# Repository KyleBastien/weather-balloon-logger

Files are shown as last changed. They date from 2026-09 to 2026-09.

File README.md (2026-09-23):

# Weather Balloon Logger LightHAB carrier

This repository contains a hand-solderable through-hole carrier for the QRP Labs LightHABTracker 1.0 and SparkFun OpenLog. LightHAB's exposed 3.3 V rail powers the logger directly.

| Directory | Contents |
| --- | --- |
| `docs/` | Electrical, mechanical, BOM, purchasing, and release records |
| `library/` | Project KiCad symbols and through-hole footprints |
| `firmware/` | LightHAB upstream integration scaffold and test plan |
| `outputs/` | Review renders, fit sheet, BOM, Gerbers, drill, DXF, and STEP |
| `scripts/` | Deterministic board rebuild, export, and audit tools |

## Project release status

This repository now contains the Weather Balloon Logger carrier design and its
review exports. It is **not yet released for fabrication** because the purchased LightHAB must be measured before its connector and mounting geometry can be finalized. See
[`docs/FABRICATION_READINESS.md`](docs/FABRICATION_READINESS.md) for the exact
engineering-prototype and flight-candidate gates.

## Working locally

The CLI needs no account and no cloud:

```bash
npm i -g copperhead
copperhead check          # ERC, DRC, and doc drift. No model, no network.
copperhead do "..."       # propose, edit, verify, commit
```

The current PCB has zero SMD pads, zero unconnected items, and a prominent no-fabrication warning in the provisional module area.

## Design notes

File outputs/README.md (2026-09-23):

# Generated review outputs

These files reflect the LightHABTracker carrier source at the current commit. They are **review artifacts, not a fabrication release** because the tracker interface and mounting geometry are provisional.

## Drawings

- `board.svg`: standard top board plot.
- `renders/weather-balloon-logger.svg`: schematic plot.
- `renders/board-full-color.svg`: colored top view including copper, through-hole pads, silkscreen, outline, and the provisional LightHAB envelope/keepouts.
- `renders/board-green-top.png`: flat green-board contrast render with no 3D component models.
- `renders/board-fit-check-1to1.pdf`: true-scale fit sheet. Print at 100% / Actual Size and verify the 90.0 × 80.0 mm outline before use.
- `board.step`: board geometry export; component-model completeness is not required for this fit stage.

The front silkscreen includes the coffee artwork and the required `UNVERIFIED LIGHTHAB FIT - DO NOT FABRICATE` warning.

## BOM and order list

- `BOM.csv` is generated from schematic MPN fields and contains 10 populated through-hole references.
- `jlcpcb-bom.csv` is a convenient grouped reference only; this project is intended for hand assembly and is not an assembly-service release.
- `fit-check-order-list.xlsx` separates safe buy-now items from held interfaces/fabrication. The three PNG files are visual checks of every worksheet.

## Gerbers

`gerbers/` is an engineering review export that also contains empty paste and back-silkscreen plots. Do not upload it wholesale. After the measured fit gate passes, create and independently inspect a fabricator-specific ZIP containing only the requested copper, mask, front silk, outline, drill, and job files.

See `../docs/FABRICATION_READINESS.md` for the remaining gates.

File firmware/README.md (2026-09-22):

# Weather Balloon Logger firmware integration scaffold

This scaffold is the carrier-side patch seed for the LightHABTracker 1.0 ATSAMD21G18 firmware. It is not a standalone, compiled flight image: the final changes must be rebased onto and built with the upstream LightHABTracker source pinned in `DEVPLAN.md`.

`docs/PINOUT.md` is the pin source of truth. Regenerate `include/pins.h` from the repository root with:

```text
python firmware/tools/generate_pins.py
```

The generator fails closed unless J2.1 remains UART TX on A1/PB08 and J2.2 remains the active-low activity LED on A2/PB09.

## Intended behavior

`WeatherBalloonLogger.ino` preloads A2 HIGH before making it an output, initializes a polling TX-only SERCOM4 UART on A1/PB08, then writes a heading and one deterministic record to OpenLog while pulsing the LED low. OpenLog TXO is unused.

LightHAB's upstream firmware—not this carrier scaffold—owns OUT1 cutdown timing, arming, and safety. No carrier code directly commands the pyro output.

## Boundaries

- `openlog` provides the proposed TX-only UART implementation without taking the occupied GPS UART.
- `telemetry_stub` marks the seam where upstream LightHAB telemetry must be supplied.
- The LED pulse reports that bytes were sent; it cannot prove that the microSD card committed them.
- A1/PB08 and A2/PB09 appeared unused in the inspected upstream source, but that must be reconfirmed during the pinned-source integration and build.

See `DEVPLAN.md` for the exact upstream baseline and qualification gates.

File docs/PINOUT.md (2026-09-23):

# Pinout — Weather Balloon Logger harness

Authoritative LightHABTracker 1.0 carrier assignment. J2 is the official known nine-position order A1, A2, 3V3, GND, SCL, SDA, SCK, MISO, MOSI. A1/PB08 is one-way OpenLog UART TX; A2/PB09 is active-low LED_N. The PCB implements this mapping with provisional connector and mounting geometry pending measurement of the purchased tracker.

## Host interface J2

| Refdes | Pin | Net | Host mapping / rationale |
| --- | --- | --- | --- |
| J2 | 1 | UART_TX | A1/PB08 one-way host TX through R4 to OpenLog RXI. |
| J2 | 2 | LED_N | A2/PB09 active-low LED sink; R2 pulls it to 3V3 so reset/high-impedance defaults D1 off. |
| J2 | 3 | 3V3 | LightHAB regulated 3.3 V for OpenLog VCC, C1/C2, the LED anode path, and R2 pull-up. |
| J2 | 4 | GND | Common signal and power return. |
| J2 | 5 | NC | Physical SCL contact intentionally unused on this carrier. |
| J2 | 6 | NC | Physical SDA contact intentionally unused on this carrier. |
| J2 | 7 | NC | Physical SCK contact intentionally unused on this carrier. |
| J2 | 8 | NC | Physical MISO contact intentionally unused on this carrier. |
| J2 | 9 | NC | Physical MOSI contact intentionally unused on this carrier. |

The A1/PB08 and A2/PB09 assignments follow the requested LightHAB interface contract. R2 is the intentional hardware reset-default-off path for the active-low LED; the former PCF8574 and cutdown-driver reset behavior no longer applies.

## Complete schematic pin/net table

| Refdes | Pin | Net | Function / intentional absence |
| --- | --- | --- | --- |
| J2 | 1 | UART_TX | A1/PB08 host TX to R4. |
| J2 | 2 | LED_N | A2/PB09 active-low LED cathode/sink node. |
| J2 | 3 | 3V3 | LightHAB regulated 3.3 V. |
| J2 | 4 | GND | Common return. |
| J2 | 5 | NC | Physical SCL contact intentionally unused. |
| J2 | 6 | NC | Physical SDA contact intentionally unused. |
| J2 | 7 | NC | Physical SCK contact intentionally unused. |
| J2 | 8 | NC | Physical MISO contact intentionally unused. |
| J2 | 9 | NC | Physical MOSI contact intentionally unused. |
| A1 | 1 | NC | BLK orientation pin intentionally unused. |
| A1 | 2 | GND | OpenLog ground. |
| A1 | 3 | 3V3 | OpenLog VCC directly from LightHAB J2.3. |
| A1 | 4 | NC | TXO intentionally unused. |
| A1 | 5 | OPENLOG_RXI | RXI receives host bytes through R4. |
| A1 | 6 | NC | GRN orientation pin intentionally unused. |
| C1 | 1 | 3V3 | OpenLog bulk bypass. |
| C1 | 2 | GND | Bypass return. |
| C2 | 1 | 3V3 | OpenLog high-frequency bypass. |
| C2 | 2 | GND | Bypass return. |
| R4 | 1 | UART_TX | Host side of UART back-power limiter. |
| R4 | 2 | OPENLOG_RXI | OpenLog receive side. |
| R1 | 1 | 3V3 | LED current-limiter supply. |
| R1 | 2 | LED_A | D1 anode feed. |
| D1 | 1 | LED_N | Cathode driven active-low by J2.2. |
| D1 | 2 | LED_A | Anode from R1. |
| R2 | 1 | 3V3 | Reset-default-off pull-up supply. |
| R2 | 2 | LED_N | 100 kΩ pull-up keeps D1 off while J2.2 is high-impedance. |
| J3 | 1 | OUT1 | LightHAB pyro output passed directly to J5.1; rating unverified. |
| J3 | 2 | GND | LightHAB pyro return passed directly to J5.2. |
| J5 | 1 | OUT1 | Direct LightHAB OUT1 cutdown output. |
| J5 | 2 | GND | Direct LightHAB pyro return. |

## Intentional absences

- No host RX path: OpenLog TXO remains unused.
- No VBATT interface or carrier logger regulator: J1 and A2 are intentionally removed because OpenLog accepts direct 3.3 V power.
- No I2C expander: U1 and C3 are intentionally removed because LightHAB A2/PB09 drives the LED directly.
- No carrier pyro driver: U2, Q1, R3, C4, and C5 are intentionally removed because LightHAB OUT1/GND passes directly to J5; its switching and current rating remain unverified.
- No carrier RF connectors or nets are present; the LightHAB onboard SMA connectors remain accessible inside the documented mechanical keepouts.
- SCL, SDA, SCK, MISO, and MOSI remain physically present on J2.5–J2.9 and are intentional no-connects.
- The schematic and PCB are synchronized electrically; the LightHAB mounting/connector geometry remains explicitly provisional and blocks fabrication.

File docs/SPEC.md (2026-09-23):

# Specification — Weather Balloon Logger carrier

This carrier adapts a LightHABTracker 1.0 to a SparkFun OpenLog, an activity LED, and a removable nichrome cutdown lead. The LightHABTracker remains the only flight computer and supplies GPS, APRS/WSPR radios, a 3×AA battery holder, two SMA connectors, and two pyro channels.

## 1. Architecture

| Item | Requirement | Status |
| --- | --- | --- |
| Host | LightHABTracker 1.0, ATSAMD21G18 | Selected |
| Flight duration | At least 4 h with GPS and flight firmware continuously available | Required; cold-load test pending |
| Battery | Three Energizer L91 AA cells in the tracker holder | Selected |
| Logger | SparkFun OpenLog DEV-13955, one-way UART receive | Selected |
| Logger supply | LightHAB J2.3 regulated 3V3, direct | Accepted assumption; bench validation required |
| Cutdown | LightHAB onboard OUT1 pyro channel passed directly to J5 | Selected; electrical rating unverified |
| Carrier assembly | All populated carrier parts directly soldered through-hole; no SMD pads | Required |

The tracker is approximately 56 × 75 mm and 36 g without batteries or antennas according to the vendor. Exact hole centers, drills, header pitch and coordinates, maximum battery-holder height, and connector/switch geometry are not published and must be measured on a purchased unit before fabrication.

## 2. Power

LightHAB accepts 2.7–16 V and carries its own 3×AA holder. The carrier does not contain a second battery holder, master switch, or logger regulator. J2.3 `3V3` directly powers OpenLog A1, C1/C2 bypass, and the activity LED path. Common ground joins J2, A1, J3, and J5. SparkFun specifies OpenLog VCC at 3.3–12 V and recommends 3.3–5 V, so 3.3 V is valid for the logger; this design accepts the unverified assumption that LightHAB can supply the approximately 20–23 mA active-write load plus transient margin.

| Parameter | Requirement |
| --- | --- |
| Mission energy | Demonstrate ≥4 h at the real cold-temperature and RF duty profile |
| OpenLog idle/write | Qualify ≤7 mA idle and ≤25 mA writing |
| LightHAB 3V3 | Remain in tolerance through OpenLog startup, card inrush, and writes |
| LED reset state | Off; R2=100 kΩ pulls active-low `LED_N` to 3V3 |
| OpenLog source | Direct J2.3 3V3; no carrier regulator |

## 3. Interfaces

### J2 — LightHAB extended pins

J2 is a directly soldered 1×9 through-hole interface in this order:

| Pin | LightHAB signal | Carrier use |
| --- | --- | --- |
| 1 | A1 / PB08 | `UART_TX` through R4 to OpenLog RXI |
| 2 | A2 / PB09 | Active-low `LED_N` |
| 3 | 3V3 | OpenLog VCC/C1/C2 plus LED supply and R2 pull-up |
| 4 | GND | Common return |
| 5 | SCL | Intentional no-connect |
| 6 | SDA | Intentional no-connect |
| 7 | SCK | Intentional no-connect |
| 8 | MISO | Intentional no-connect |
| 9 | MOSI | Intentional no-connect |

A1/PB08 and A2/PB09 appear unused in the reviewed upstream firmware at commit `797b78d120b0e844f60798b88dfa3735f27e89da`, but integration must be rebased and retested against the exact firmware shipped on the purchased tracker.

### OpenLog and activity LED

OpenLog is receive-only: J2.1 → R4 1 kΩ → A1 RXI. A1 TXO is intentionally unused. J2.3 supplies 3.3 V directly to A1 VCC and local C1/C2 bypass. The LED path is 3V3 → R1 1 kΩ → D1 → `LED_N`; firmware drives J2.2 low during activity. R2 keeps it off while the pin is high-impedance at reset. Activity indicates firmware intent to log, not confirmed SD media completion.

### Cutdown

J3 receives LightHAB OUT1/GND and connects directly to the same pins on J5, a horizontal JST-XH connector. The carrier adds no MOSFET, gate driver, or high-current power path. OUT1 polarity, switching topology, pulse duration, current capability, default state, and fault behavior are **UNVERIFIED**. Do not connect nichrome until those properties and the complete harness are bench-tested with a current-limited supply and inert load.

### Antennas

Both antenna connections remain entirely on the LightHABTracker. The carrier contains no SMA connector and no RF trace. The PCB must keep mechanical clearance below and around both onboard SMA connectors and their cable bend volumes.

## 4. Firmware allocation

- A1/PB08: SERCOM4 UART TX to OpenLog.
- A2/PB09: active-low activity LED; write HIGH before configuring OUTPUT to avoid a reset flash.
- LightHAB D4/D5 and the vendor pyro implementation remain owned by upstream firmware. OUT1 is selected for cutdown.
- SCL, SDA, SCK, MISO, and MOSI are not used by the carrier.
- The local firmware is an integration/qualification scaffold, not a replacement for the complete LightHAB flight firmware.

## 5. Mechanical and environment

The carrier outline is 90 × 80 mm. Reserve a provisional 56 × 75 mm LightHAB zone on the right side with the LightHAB component face outward and its battery holder between module and carrier. Use provisional 18–20 mm board-to-board clearance. Place carrier parts on the left wing and keep the OpenLog microSD card accessible. Align the LightHAB USB connector and two SMA connectors with board edges and preserve plug/cable access.

All LightHAB mounting holes and mating interface pads in this revision are photo-derived placeholders and must be labeled **UNVERIFIED — DO NOT FABRICATE**. Final placement requires a purchased module or an official dimensioned drawing.

Qualification temperature remains −40 °C to +40 °C unless the mission profile establishes a wider range. Cold-soak the complete powered stack, batteries, logger, SD card, connectors, and cutdown harness.

## 6. Release gates

Before a fit-test PCB:

1. Measure the LightHAB outline, four hole centers and drills, 1×9 pitch/coordinates/drills, J3 pad coordinates/drills, holder height, and maximum component height.
2. Confirm mounting orientation and USB/SMA/cable access.
3. Confirm LightHAB 3V3 remains in tolerance while OpenLog starts and writes at the cold/voltage extremes.
4. Confirm OUT1/GND polarity, voltage, current limit, switching topology, default state, and supported pulse duration.
5. Reconcile those measurements into the footprint, reroute, and regenerate 1:1 plots.

Before fabrication, additionally complete DRC/ERC, footprint-vs-purchased-part checks, cold/power tests, pyro firing tests, firmware integration tests, and a physical 1:1 paper fit check. Until those gates pass, generated fabrication files are engineering previews only.

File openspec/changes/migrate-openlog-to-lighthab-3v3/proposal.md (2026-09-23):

# Proposal: migrate-openlog-to-lighthab-3v3

> Marker: AUTO (autonomous mode; auto-approved, reviewable after the fact)

## Why

The user accepts direct OpenLog power from LightHAB J2.3 3V3, eliminating the separate VBATT-fed Pololu regulator path and its obsolete fixed-5V claims while retaining a bench-validation gate for the unverified host-rail capacity.

## What Changes

- Remove J1, A2, VBATT, and LOGGER_5V from schematic intent and schematic capture.
- Connect A1.3, C1.1, C2.1, R1.1, and R2.1 to the existing J2.3 3V3 net.
- Preserve UART, active-low LED, J3/J5 OUT1, GND, intentional no-connects, and through-hole choices.
- Update BOM, specification, subsystem, pinout, and affected constraint entries to describe direct LightHAB 3V3 power.
- Record SparkFun OpenLog VCC as 3.3–12 V, recommended 3.3–5 V, with about 20–23 mA active-write current; retain LightHAB 3V3 capacity as an accepted assumption requiring bench validation.
- Remove J1/A2 from the PCB, route J2.3 directly to A1/C1/C2, update the 3V3 silkscreen label, and regenerate all review/manufacturing outputs.
- Synchronize the BOM, fit-check order workbook, readiness checklist, footprint audit, and deterministic build/export scripts; leave firmware and historical change records intact except for new append-only entries.

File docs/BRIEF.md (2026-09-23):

# Weather Balloon Logger carrier brief

Build a hand-solderable through-hole carrier around the QRP Labs LightHABTracker 1.0. LightHAB remains the GPS/APRS/WSPR host, supplies its own 3×AA battery holder and antenna connectors, and owns the two pyro outputs.

The carrier shall:

- mount the tracker once its exact geometry is measured;
- power a SparkFun OpenLog with headers directly from LightHAB J2.3 3V3, accepting the host-rail-capacity assumption until bench validation;
- send telemetry from A1/PB08 to OpenLog RXI through a 1 kΩ series resistor;
- use A2/PB09 as an active-low write-attempt LED with a hardware 100 kΩ reset-default-off pull-up;
- pass LightHAB OUT1/GND directly to a soldered JST-XH cutdown connector;
- contain only through-hole soldered parts, with no SMD pads or carrier RF routing;
- preserve access/keepouts for LightHAB USB, SMA connectors, battery holder, and solder joints;
- remain explicitly blocked from fabrication until the purchased tracker is measured and passes a 1:1 exact-parts fit check.

The carrier does not provide sockets, a second battery holder, a second power switch, an I²C expander, an external pyro MOSFET/driver, or carrier SMA connectors.

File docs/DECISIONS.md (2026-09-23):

- 2026-09-16 Use the exact C&K `7101SYZQE` and hand-solder its `Z` lugs directly into project footprint `WeatherBalloon:SW_CK_7101SYZQE`. Use 2.30 x 1.10 mm plated slots on 4.70 mm centers for the published nominal 2.03 x 0.76 mm lugs, and link the matching downloaded STEP model. Model the top-side SparkFun OpenLog with `WeatherBalloon:SparkFun_OpenLog_DEV-13712_Carrier`, whose 15.24 x 19.05 mm body comes from SparkFun's official dimensional drawing. | why: All off-board parts are intentionally direct-soldered for home assembly; the slot footprint preserves that choice while adding practical insertion clearance. The generic OpenLog header footprint omitted the module body and Copilot's 23 x 14 mm size was incorrect. | affects: SW1, A1, fp-lib-table, library/, schematic.intent.json, weather-balloon-logger.kicad_sch, docs/FOOTPRINT_AUDIT.md, next Copperhead layout pass
- 2026-09-15 [run 2026-09-15T20-57-58-683Z] Size the flight pack as 3s L91 for energy; allow 4s only if LightAPRS-W 2.0 UVLO/VIN cannot run to 3s EOD (3.0 V). Do not add cells for amp-hours. | why: Series cells do not add mAh; ASSUMED 800 mAh flight load vs ≥1600 mAh usable after cold derate is already met by one L91 string. | affects: docs/SPEC.md §2.1–2.2, power.series_cells, power.flight_energy_mAh, power.pack
- 2026-09-15 [run 2026-09-15T20-57-58-683Z] Prefer a low-side MOSFET that is fully enhanced at 3.3 V Vgs for nichrome cutdown; do not commit IRLZ44N or a 3.3 V relay module without an explicit later decision. | why: IRLZ44N Rds(on) is specified at 5 V Vgs so it may not fully turn on from the ATSAMD21G18 3.3 V GPIO; a relay adds coil Iq and vibration risk versus a specified logic-level FET plus intentional gate pulldown. | affects: docs/SPEC.md §5, cutdown.vgs_fully_on_V, cutdown.load_current_A, docs/BOM.md
- 2026-09-15 [run 2026-09-15T20-57-58-683Z] This PCB is a harness only: no second MCU, no carrier RTC, no USB-serial bridge, no L91 charger, no 5 V USB as a flight source. | why: Firmware, GPS, and radios live on LightAPRS-W 2.0; OpenLog is the logger; L91 cells are primary. Missing those blocks is intentional, not an omission. | affects: docs/SPEC.md §4, §6, §8
- 2026-09-15 [run 2026-09-15T22-37-07-258Z] Freeze the carrier as a harness-only block diagram in docs/SUBSYSTEMS.md: 3s L91 (4s only if host UVLO), SW1 breaks pack+, VIN to LightAPRS-W 2.0, 3V3 fan-out to OpenLog/LED/FET gate, UART to OpenLog, dual downward 50 Ω SMA, low-side logic-level cutdown FET with intentional gate pulldown; no GPIO assignments this stage. | why: Locks SPEC budgets before schematic so a later part cannot satisfy voltage/package while blowing Iq, Vgs-at-3.3 V, strapping, or SMA keepout; IRLZ44N and 3.3 V relay remain uncommitted. | affects: docs/SUBSYSTEMS.md, docs/SPEC.md §1–§8, power.*, cutdown.*, antenna.*, openlog.vcc_V, docs/PINOUT.md (intentionally absent)
- 2026-09-15 [run 2026-09-15T23-48-22-724Z] Represent the off-board LightAPRS-W 2.0 at J2 with installed Connector_Generic:Conn_01x07 and represent A1 OpenLog with installed Connector_Generic:Conn_01x06; do not invent unavailable named module symbols or assign host GPIOs in part selection. | why: Neither module name exists in the installed KiCad 10 libraries, while the installed generic connector symbols expose authoritative pins and preserve a capturable stage-4 design pending the mandatory strapping check. | affects: docs/BOM.md, J2, A1, future docs/PINOUT.md and schematic capture
- 2026-09-15 [run 2026-09-15T23-48-22-724Z] Select Q1 AO3400A in SOT-23 as the conditional cutdown FET and SW1 7101MD9CQE as the conditional pack-positive mechanical switch, with every MPN remaining UNVERIFIED until the BOM acceptance checks pass. | why: AO3400A has an installed exact symbol with G/S/D pins 1/2/3 and is specified in the 2.5–3.3 V gate-drive class, unlike IRLZ44N; the switch path must be verified for the full 2 A burst and true pack-positive disconnect. | affects: docs/BOM.md, Q1, SW1, cutdown.vgs_fully_on_V, cutdown.load_current_A, power.switch_off_current_uA
- 2026-09-15 [run 2026-09-15T23-53-19-080Z] Keep LightAPRS-W 2.0 and OpenLog as off-board functional parts but capture them through tool-verified installed generic connector symbols; normalize D1's schematic Value to the component value LTST-C190KGKT and keep descriptive text only in the BOM Rationale. | why: Named LightAPRS-W 2.0 and OpenLog symbols are absent from this KiCad 10 installation, while the selected connector, switch, coax, AO3400A, LED, resistor, and capacitor symbols have authoritative single-unit package pins; component-only Values prevent stage-4 text collisions. | affects: docs/BOM.md; J2; A1; D1; future stage-4 schematic capture
- 2026-09-15 [run 2026-09-15T23-55-27-968Z] Retain the complete stage-3 BOM selections and capture the unavailable named LightAPRS-W 2.0 and OpenLog modules through freshly verified installed generic connector symbols; keep every MPN UNVERIFIED and every host GPIO unassigned. | why: Fresh library searches confirm the named module symbols are absent while the selected connector, coax, switch, AO3400A, LED, resistor, and capacitor lib_ids have authoritative package pins; deferring GPIOs preserves the mandatory strapping check and the BOM acceptance holds preserve the 2 mA idle and leakage budgets. | affects: docs/BOM.md; J1-J5; SW1; A1; Q1; D1; R1-R3; C1-C2; future docs/PINOUT.md and schematic capture
- 2026-09-16 [run 2026-09-16T02-41-32-150Z] Assign LightAPRS A1/PB08 to one-way SERCOM4 UART_TX and A0 to CUTDOWN_CTRL; leave J2 pins 5–6 and OpenLog TXO intentionally unconnected. | why: Only A0 and A1 are confirmed free dedicated GPIOs; OpenLog receive-back is optional, while cutdown requires an independent default-off control without reusing occupied GPS, radio, I2C, or SPI pins. | affects: J2, A1, UART_TX, CUTDOWN_CTRL, docs/PINOUT.md, docs/BOM.md, docs/SPEC.md, docs/SUBSYSTEMS.md
- 2026-09-16 [run 2026-09-16T02-41-32-150Z] Wire the write-activity indicator as 3V3 through R1 and D1 into UART_TX, so idle-high is OFF and low transmitted bits illuminate D1. | why: This produces a visible indication for every transmitted log record while using no third host GPIO and preserving the LED-off leakage budget; it is explicitly a transmit proxy rather than proof of SD-media commit. | affects: D1, R1, UART_TX, LED_A, docs/PINOUT.md, docs/BOM.md, docs/SPEC.md, docs/SUBSYSTEMS.md
- 2026-09-16 [run 2026-09-16T02-41-32-150Z] Accept the deterministic drafter's synthesized copperhead_power rail and PWR_FLAG symbols as engine-local infrastructure, while treating the 15 BOM symbols as the procurement-relevant symbol set. | why: verify_symbols confirmed all BOM library symbols and pins; its remaining wrong/no-library messages refer only to generated named-rail helpers, and substituting suggested converter or diode parts would be electrically false. | affects: weather-balloon-logger.kicad_sch, PACK_IN, PACK_SW, 3V3, GND, CUTDOWN_DRAIN
- 2026-09-16 [run 2026-09-16T02-51-31-754Z] Use an 80 × 70 mm first-draft outline with J1/J5 on the left edge, J2 on the top edge, and J3/J4 on the bottom payload-facing edge; keep the OpenLog/decoupling cluster near J2, the cutdown cluster near J5, and J6 centered between the two RF branches. | why: This separates high-current cutdown hardware from the two ≥5 mm SMA clearance envelopes while keeping decoupling, gate control, and RF stubs locally short. | affects: weather-balloon-logger.kicad_pcb, J1-J6, A1, C1-C2, Q1, R1-R3, D1, LAYOUT.md
- 2026-09-16 [run 2026-09-16T02-51-31-754Z] Mark every inline stage-5 land pattern as board-local `CopperheadDraft_*` geometry and reserve ESD space without adding uncaptured protection devices. | why: The available workflow can create a DRC-clean coordinate study but cannot truthfully claim hand-authored placeholder pads are verified library/manufacturer land patterns; ESD parts also require leakage, voltage, RF-capacitance, schematic, and BOM decisions before placement. | affects: weather-balloon-logger.kicad_pcb, LAYOUT.md, future schematic/BOM footprint and ESD qualification
- 2026-09-16 [run 2026-09-16T03-07-33-386Z] Preserve the committed Stage 5 coordinate-level board draft after successful readback; do not recreate or reroute it during recovery. Treat every CopperheadDraft_* footprint, the drawn RF clearance envelopes, and the reserved ESD areas as explicitly non-fabrication-ready placeholders exactly as disclosed in LAYOUT.md. | why: The recovered board and LAYOUT.md contain the requested placement, critical routing, keepout intent, and Draft quality disclosure; rebuilding would add risk without correcting a failed artifact. | affects: weather-balloon-logger.kicad_pcb, LAYOUT.md, PCB SVG render, and future footprint/RF/ESD qualification
- 2026-09-16 [run 2026-09-16T03-08-59-062Z] Preserve the recovered Stage 5 coordinate-level PCB draft without rerouting or recreating it; treat all CopperheadDraft_* footprints, drawn RF clearance envelopes, and reserved ESD areas as explicitly non-fabrication-ready exactly as disclosed in LAYOUT.md. | why: Readback confirms the existing PCB already contains the requested 80 × 70 mm placement, edge connectors, local decoupling/cutdown/LED clusters, critical routing, RF envelopes, and a complete Draft quality disclosure, so reconstruction would add risk without fixing a demonstrated defect. | affects: weather-balloon-logger.kicad_pcb, LAYOUT.md, exported PCB SVG, docs/DECISIONS.md
- 2026-09-16 [run 2026-09-16T03-15-06-670Z] Generate the Stage 6 fabrication, outline, STEP, SVG, and consolidated BOM artifacts as pipeline outputs only, retaining every MPN UNVERIFIED marker and an explicit no-fabrication and no-procurement hold. | why: The exports are required for pipeline completeness, but the board still uses placeholder land patterns and has unresolved RF, mechanical, thermal, leakage, temperature, and sourcing qualifications. | affects: outputs/, outputs/BOM.csv, outputs/README.md, weather-balloon-logger.kicad_pcb, docs/BOM.md, docs/LAYOUT.md
- 2026-09-16 [run 2026-09-16T03-17-06-012Z] Use an Arduino SAMD scaffold with vendor CMSIS register access for a polling, transmit-only SERCOM4 UART on A1/PB08; make cutdown initialization on A0-low the first application action and provide a reproducible docs/PINOUT.md-to-pins.h generator. | why: This follows the verified two-pin allocation without stealing the occupied GPS UART or inventing an RX/A2 connection, while preserving reset-time cutdown safety and keeping PINOUT.md authoritative. | affects: firmware/, docs/PINOUT.md, UART_TX, CUTDOWN_CTRL, SERCOM4, A0, A1/PB08
- 2026-09-16 [run 2026-09-16T03-22-16-658Z] Gate hardware bring-up and prototype ordering through unpowered continuity, current-limited power, host/3V3, default-off cutdown, OpenLog/UART, RF, dummy-load, nichrome, environmental, and four-hour mission tests in that order; use existing pads/pins as probe locations and keep the current PCB/MPN fabrication and procurement holds. | why: The ordered gates expose shorts, wrong pinouts, excess idle current, reset-time cutdown hazards, RF defects, and thermal failures before energetic or expensive testing, while avoiding any false implication that draft footprints or UNVERIFIED MPNs are production-ready. | affects: docs/DEVPLAN.md, docs/CHANGELOG.md, prototype procurement, PCB fabrication release, PACK_IN, PACK_SW, 3V3, UART_TX, CUTDOWN_CTRL, CUTDOWN_GATE, CUTDOWN_DRAIN, RF_APRS, RF_WSPR
- 2026-09-16 [run 2026-09-16T04-40-13-377Z] Replace the abstract 7-pin J2 with the verified 11-position LightAPRS-W edge-header order; assign J2.3 A1/PB08 to one-way UART_TX and J2.4 A2/PB09 to direct cutdown, and represent VHF/HF as separate J6/J7 corner contacts. | why: The verified physical module exposes A2/PB09 and places VHF/HF at opposite corners, so the former A0/7-pin/two-pin-RF abstraction could not produce a mechanically or electrically faithful carrier. | affects: J2, J6, J7, UART_TX, CUTDOWN_CTRL, RF_APRS, RF_WSPR, docs/PINOUT.md, docs/BOM.md, firmware pin contract
- 2026-09-16 [run 2026-09-16T04-40-13-377Z] Add U1 PCF8574T at I2C address 0x20 with A0/A1/A2 low, P0 as active-low D1 control, P1–P7 reserved no-connect, INT unused, and C3 100 nF local decoupling. | why: Moving visual indicators to the shared I2C bus preserves A1 for OpenLog and A2 for deterministic direct cutdown while providing seven future GPS-status LED outputs; power-up-high ports keep D1 off at reset. | affects: U1, C3, D1, R1, I2C_SCL, I2C_SDA, LED_N, 3V3, GND
- 2026-09-16 [run 2026-09-16T04-40-13-377Z] Retain the 2.00 mA board-added idle ceiling by allocating at most 1.85 mA to OpenLog, 0.10 mA to U1, and 0.05 mA to all remaining passive/FET/LED-off leakage. | why: Adding an always-powered expander without tightening the former 1.95 mA OpenLog allowance would exceed the documented idle-current budget at worst-case maxima. | affects: power.board_added_idle_mA, power.openlog_idle_mA, power.led_expander_idle_uA, A1, U1, docs/SPEC.md, docs/BOM.md
- 2026-09-16 [run 2026-09-16T04-40-13-377Z] Retain the deterministic drafter's copperhead_power rail and PWR_FLAG helpers unchanged after the host-interface revision. | why: verify_symbols confirms the functional installed symbols including PCF8574T; its remaining library findings are only the already-documented engine-local named-rail infrastructure, and substituting suggested converters, diodes, or crystals would be electrically false. | affects: weather-balloon-logger.kicad_sch, 3V3, GND, PACK_IN, PACK_SW, CUTDOWN_DRAIN, PWR_FLAG
- 2026-09-16 [run 2026-09-16T05-01-15-431Z] Reserve the 32 × 55 mm LightAPRS-W zone at PCB coordinates (124,101)–(156,156), place the direct-mating J2 row on its left long edge, place J6 VHF and J7 HF at opposite lower corners, and keep every other electrical component outside; add four approximate M2 standoff holes pending physical-board confirmation. | why: This permits direct module plug-in while preventing body collisions and preserving outward, separated RF paths to the two bottom-edge SMA jacks. | affects: weather-balloon-logger.kicad_pcb, J2, J6, J7, H1-H4, J3, J4, docs/LAYOUT.md, docs/SUBSYSTEMS.md
- 2026-09-16 [run 2026-09-16T05-47-26-045Z] Use the exact 32.77 x 54.80 mm FACE-UP LightAPRS-W zone with J2 on the matching right long edge, J7/HF bottom-left, J6/VHF bottom-right, J4/WSPR on the left board edge, and J3/APRS on the right board edge; rotate the vendor drawing's approximately 42.73 mm long-axis hole span onto the PCB vertical axis. | why: Direct top-view reproduction prevents the prior left-right mirror error, preserves J6-to-J3 and J7-to-J4 electrical mappings, and gives short uncrossed RF launches while fitting the hole pattern within the 32.77 mm module width. | affects: weather-balloon-logger.kicad_pcb, docs/LAYOUT.md, mechanical.lightaprs_module_zone, J2, J3, J4, J6, J7, H1-H4, RF_APRS, RF_WSPR
- 2026-09-16 [run 2026-09-16T06-19-14-171Z] Place H1-H4 at the measured module coordinates and center J2's exact 2.548 mm-pitch span at x=154.9; shift J7/J6 outward to x=123.7/156.3 at y=154.5 so their copper clears H3/H4 while retaining HF-left and VHF-right. | why: The requested measured hole rectangle and approximate RF-contact centers geometrically conflict, so the RF contacts must move outward slightly to preserve hole clearance without swapping the verified RF mapping. | affects: weather-balloon-logger.kicad_pcb, docs/LAYOUT.md, mechanical.lightaprs_module_zone, H1-H4, J2, J6, J7, RF_APRS, RF_WSPR
- 2026-09-16 [run 2026-09-16T06-19-14-171Z] Move J7/HF and J6/VHF 0.5 mm farther toward the module bottom edge and reroute J2/U1 ground returns around the I2C conductors. | why: The first measured-coordinate placement missed the 0.25 mm NPTH hole-clearance rule and created B.Cu SCL/SDA crossings; the adjusted positions preserve RF side mapping and satisfy explicit DRC geometry. | affects: weather-balloon-logger.kicad_pcb, docs/LAYOUT.md, mechanical.lightaprs_module_zone, J2, J6, J7, I2C_SCL, I2C_SDA, GND, RF_APRS, RF_WSPR
- 2026-09-16 [run 2026-09-16T07-14-10-279Z] Place the horizontal, right-reading `JAVAS Logger` label on F.SilkS centered at (114.5, 118.0) mm using 1.8 mm text and a 0.30 mm stroke. | why: The left-center location is readable while remaining above the reserved ESD area, left of the LightAPRS-W module zone, outside both SMA keepouts, and clear of components, pads, traces, and H1-H4. | affects: weather-balloon-logger.kicad_pcb, docs/LAYOUT.md
- 2026-09-16 [run 2026-09-16T23-23-26-534Z] Place J1 at (107,108) 90°, J5 at (110,141) 90°, and SW1 at (114,108) 0° while retaining their exact real footprints; keep SW1 pad 2 as PACK_IN, pad 1 as PACK_SW, and pad 3 intentionally unconnected. | why: These are the minimum inward/rightward moves that contain all three real courtyards, keep the JST side-entry openings and toggle accessible for hand assembly, and avoid moving any other footprint or changing the outline. | affects: weather-balloon-logger.kicad_pcb; J1; J5; SW1; PACK_IN; PACK_SW; GND; CUTDOWN_DRAIN; docs/FOOTPRINT_AUDIT.md; docs/LAYOUT.md
- 2026-09-16 [run 2026-09-16T23-23-26-534Z] Retain J1 at (103,108) 90° and J5 at (103,141) 90° after exact rotated-courtyard evaluation; move only SW1 to (114,108) 0°, route PACK_SW around SW1 pad 3 and adjacent connector pads, and move only SW1's colliding nonfunctional silk to F.Fab. | why: The first normal DRC proved both JST courtyards already fit at their original edge positions, while the true conflicts came from SW1 clearance and diagonal copper approaches across neighboring through-hole pads. | affects: J1; J5; SW1; PACK_IN; PACK_SW; GND; CUTDOWN_DRAIN; weather-balloon-logger.kicad_pcb; docs/FOOTPRINT_AUDIT.md; docs/LAYOUT.md
- 2026-09-16 [run 2026-09-16T23-31-10-944Z] Place the exact top-side solder-down OpenLog carrier A1 at (171,110) with C1/C2 retained at (168,114)/(164,114), and extend only the board top edge from y=100 to y=91.5. | why: This is the minimum coherent geometry change that puts A1's official body and courtyard outside the fixed LightAPRS zone, exposes the microSD end at an edge, preserves short bypass connections, and leaves all fixed module and RF placement untouched. | affects: weather-balloon-logger.kicad_pcb; A1; C1; C2; GND; 3V3; UART_TX; docs/LAYOUT.md; docs/FOOTPRINT_AUDIT.md
- 2026-09-16 [run 2026-09-16T23-38-07-526Z] Keep J3 at (168,162) and J4 at (112,162) with their exact SMA_Amphenol_132134_Vertical footprints; bring each 0.5 mm RF trace into pad 1 along the connector centerline and join all four pad-2 shields with a symmetric 1.0 mm B.Cu U-fanout to the existing bottom GND trunk. | why: Centerline entry clears the real shield pads and the balanced local fanout removes every dangling/unconnected shield with the smallest routing-only change; released-stackup impedance design, final return vias, and VNA validation remain mandatory. | affects: weather-balloon-logger.kicad_pcb; J3; J4; RF_APRS; RF_WSPR; GND; docs/LAYOUT.md; docs/FOOTPRINT_AUDIT.md
- 2026-09-17 [run 2026-09-17T00-49-26-287Z] Fix the flight pack at exactly three series Energizer L91 cells at 3.0–5.4 V, keep LightAPRS RAW/J2.1 and cutdown J5.1 directly on switched PACK_SW, and dedicate Pololu S7V8F5 item 2123 to OpenLog only with VIN and SHDN on PACK_SW, GND common, and fixed LOGGER_5V from VOUT to A1 VCC. | why: This preserves uninterrupted GPS and the unregulated high-current cutdown path while isolating OpenLog from the LightAPRS 3V3 rail within realistic logger current limits. | affects: current authoritative documentation, constraint registry, BOM, PACK_SW, LOGGER_5V, A1 VCC; schematic and PCB implementation intentionally deferred
- 2026-09-17 Capture A2 and R4 in the schematic while deferring only PCB placement/routing. | why: A deterministic schematic checkpoint proves the split-power and UART back-power contracts before changing crowded board copper. | affects: A2, R4, A1, C1, C2, PACK_SW, LOGGER_5V, UART_TX, OPENLOG_RXI, schematic.intent.json, weather-balloon-logger.kicad_sch
- 2026-09-17 Place A2 at (106,121) 270° and R4 at (159.8,113.3) 90° without moving existing footprints or enlarging the outline. | why: This is the DRC-proven position that clears SW1/J1/J5/R2, the fixed LightAPRS body, and both RF reservations while keeping switched-pack input local and OpenLog UART isolation close to A1. | affects: weather-balloon-logger.kicad_pcb, A2, R4, PACK_SW, LOGGER_5V, GND, UART_TX, OPENLOG_RXI
- 2026-09-17 Replace R4's 0603 footprint with a horizontal DIN0207 axial through-hole footprint on 7.62 mm pitch at (166.62,118), 180°. | why: R4 must be installable as a leaded part through drilled holes for straightforward hand soldering; the new position clears surrounding module and copper geometry. | affects: R4, schematic.intent.json, weather-balloon-logger.kicad_sch, weather-balloon-logger.kicad_pcb, UART_TX, OPENLOG_RXI
- 2026-09-17 [run 2026-09-17T04-30-30-449Z] Move only C4 to (111,125) and C5 to (106.5,129.5), retain their -90 degree orientation, reconnect only LOGGER_5V/GND locally, replace the two KEMET footprint silk rectangles with pad-clear top/bottom strokes, and hide only the colliding U1/R4/C5/R3/Q1/U2 references. | why: These bounded changes clear the reported courtyard, PTH, and legend conflicts without altering pads, fab/courtyard geometry, outline, RF routing, or functional topology. | affects: weather-balloon-logger.kicad_pcb; library/WeatherBalloon.pretty/KEMET_C315C104K5R5TA.kicad_mod; library/WeatherBalloon.pretty/KEMET_C322C475K5R5TA.kicad_mod; C1-C5; C4/C5 LOGGER_5V and GND; U1/R4/J5/U2/R3/Q1/A2 local legend
- 2026-09-17 [run 2026-09-17T04-30-30-449Z] Correct the final cleanup placement to C4 at (109,132.3) with -90 degree orientation and C5 at (106.5,148) with 0 degree orientation; keep C4 adjacent to U2 and C5 entirely above the RF/ESD reservation. | why: The initial candidate intersected A2 and PACK_SW; these corrected coordinates use the DRC-proven free regions beside and below the driver while preserving all fixed footprints and functional nets. | affects: weather-balloon-logger.kicad_pcb; C4; C5; LOGGER_5V; GND
- 2026-09-17 [run 2026-09-17T04-30-30-449Z] Use the final mechanically clean bypass placement C4=(108,133.3) at 0 degrees and C5=(103,115.5) at 0 degrees, with only short local LOGGER_5V/GND connections to existing trunks. | why: Rotating C4 fits it between the fixed A2 and J5 courtyards while keeping it closest to U2; C5 fits between fixed J1 and A2 and stays outside the cutdown and RF reservations. | affects: weather-balloon-logger.kicad_pcb; C4; C5; LOGGER_5V; GND
- 2026-09-17 [run 2026-09-17T04-30-30-449Z] Set the final C4 position to (107.7,133.3) and hide its reference text. | why: A 0.3 mm left shift clears the fixed CUTDOWN_DRIVE trace while retaining the mechanically clean A2/J5/U2 gaps; hiding the reference removes the final A2 legend collision without altering functional silk geometry. | affects: weather-balloon-logger.kicad_pcb; C4; LOGGER_5V; GND; local F.SilkS
- 2026-09-17 [run 2026-09-17T04-30-30-449Z] Correct docs/PINOUT.md to show the existing captured cutdown-driver nets: R2.1=CUTDOWN_DRIVE, Q1.2=CUTDOWN_DRAIN, and Q1.3=GND. | why: The drift checker exposed stale documentation from the earlier direct-drive/AO3400 mapping; the schematic and functional topology remain unchanged. | affects: docs/PINOUT.md; R2; Q1; CUTDOWN_DRIVE; CUTDOWN_DRAIN; GND
- 2026-09-17 [run 2026-09-17T05-14-18-458Z] Add only compact F.SilkS functional and polarity text around the existing placed hardware, preserving every reference designator and all electrical/mechanical geometry. | why: Human-readable field and assembly cues reduce battery, cutdown, module, and RF-port connection errors without changing the verified design. | affects: weather-balloon-logger.kicad_pcb F.SilkS; docs/LAYOUT.md
- 2026-09-17 Refine the functional legend against the assembled 3D view: keep POWER SWITCH and 5V REG visible after installation, mark J5 directly with plus/minus, shorten its CUTDOWN caption, and identify the remote driver caption as `U2 DRIVER - LEFT DIP`. Omit engineering User layers from the color presentation SVG. | why: DRC clearance alone does not guarantee that labels are visible, correctly associated, or uncluttered after assembly. | affects: weather-balloon-logger.kicad_pcb F.SilkS; outputs/renders/board-full-color.svg; docs/LAYOUT.md; outputs/README.md
- 2026-09-21 Use a 90 × 80 mm carrier with a provisional 56 × 75 mm right-side LightHAB zone, components facing outward, the battery holder between boards, and an 18–20 mm provisional stack. | why: Published overall dimensions support an architecture draft, while absent hole/interface dimensions require a visible no-fabrication hold. | affects: weather-balloon-logger.kicad_pcb, J1-J3, H1-H4, docs/LAYOUT.md
- 2026-09-21 Remove all carrier RF and discrete pyro-driver hardware; pass LightHAB OUT1/GND directly from J3 to J5 and reserve only mechanical SMA/USB clearance. | why: LightHAB integrates both radios, SMA connectors, battery holder, and pyro channels; duplicating those blocks would add unverified wiring and inaccessible parts. | affects: J3, J5, OUT1, GND, PCB keepouts
- 2026-09-21 Generate the provisional PCB with a deterministic KiCad Python script and require clean KiCad ERC/DRC, zero unconnected items, zero SMD pads, and visual review. | why: Copperhead validated the bounded proposal but stalled while reasoning over the legacy 6,000-line board, so deterministic regeneration provides a reproducible and independently checked result. | affects: scripts/rebuild_lighthab_board.py, weather-balloon-logger.kicad_pcb
- 2026-09-21 Keep LightHAB's vendor firmware solely responsible for OUT1 cutdown control; the carrier firmware uses A2/PB09 only as an active-low logger activity LED and initializes it HIGH-before-output. | why: The new tracker already contains the pyro channels, so duplicate carrier firing logic creates conflicting ownership and an avoidable safety path. | affects: firmware/, J2.2, D1, R2, J3, J5
- 2026-09-21 Treat all generated manufacturing files as review-only until a purchased LightHABTracker supplies measured connector, hole, battery-holder, USB, and SMA geometry. | why: Public overall dimensions are insufficient to release a mating carrier footprint. | affects: docs/FABRICATION_READINESS.md, outputs/, J1-J3, H1-H4
- 2026-09-22 Remove J1 and A2 and power OpenLog A1 plus C1/C2 directly from LightHAB J2.3 3V3. | why: SparkFun permits 3.3 V OpenLog operation and the user explicitly accepts the unverified LightHAB rail-capacity assumption; removing the separate VBATT/regulator path reduces the carrier part count and interfaces. Bench validation under logger and radio load remains mandatory. | affects: J1, A2, A1, C1, C2, 3V3, VBATT, LOGGER_5V, schematic, PCB, BOM, order list, fabrication gates

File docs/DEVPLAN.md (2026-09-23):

# Development and qualification plan

## Current design

The carrier mounts a LightHABTracker 1.0, powers an OpenLog directly from LightHAB J2.3 3V3, provides an active-low write-attempt LED, and passes LightHAB OUT1/GND directly to J5. The tracker retains its onboard 3×AA holder, dual SMA connectors, radios, GPS, and pyro control. The carrier adds no RF path, logger regulator, or pyro driver.

## Next bounded revision: measured mechanical fit

1. Purchase and photograph the exact LightHABTracker.
2. Record all dimensions listed in `FABRICATION_READINESS.md` with a caliper and annotated photos.
3. Confirm J2.3 3V3 capacity and OUT1 electrical behavior on a protected bench setup.
4. Replace provisional J2/J3 and H1-H4 geometry in `scripts/rebuild_lighthab_board.py`; select exact interface MPNs.
5. Rebuild the PCB, preserve the 90 × 80 mm outline unless measurements demand a documented change, and check USB/SMA/battery envelopes.
6. Print the 1:1 fit sheet and perform the exact-parts physical overlay.
7. Regenerate all sources, BOM/order list, renders, and review outputs. Remove the warning only when evidence closes the fit gate.

## Electrical bring-up

1. With LightHAB and OpenLog disconnected, inspect soldering and verify no shorts between 3V3, OUT1, and GND.
2. Current-limit the bench supply and confirm 3.3 V at A1 VCC before installing OpenLog.
3. Confirm the rail stays in tolerance during OpenLog startup and sustained writes, including representative radio activity; confirm R4 limits unwanted UART back-power current.
4. Confirm D1 is off at reset and active only when A2/PB09 is driven low.
5. Test J5 using an inert load and the vendor firmware's OUT1 controls. The carrier does not increase the output rating.

## Flight qualification

Follow `firmware/DEVPLAN.md` for software integration. Qualify the exact 3S L91 set, logger current, radio duty, antennas, thermal/vacuum behavior, cutdown assembly, and four-hour mission profile. Preserve raw measurements and stop on unexplained resets, heating, rail droop, radio degradation, or unexpected pyro activation.

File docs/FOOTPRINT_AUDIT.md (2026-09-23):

# Through-hole footprint audit

Date: 2026-09-22

## Result

The PCB contains 10 populated electrical references, four NPTH mounting holes, and one padless silkscreen-art footprint. Automated inspection reports 35 pads (31 plated through-hole and four NPTH) and **zero SMD pads**. KiCad reports zero footprint errors, zero DRC violations, and zero unconnected items.

Every populated carrier component is intended for direct through-hole soldering. There are no surface-mount lands, castellated pseudo-pads, test-pad-only connections, or carrier SMA pads.

## Electrical footprints

| Refs | Footprint | Status |
| --- | --- | --- |
| A1 | `WeatherBalloon:SparkFun_OpenLog_DEV-13712_Carrier` | Verified against SparkFun 15.24 × 19.05 mm module drawing; confirm purchased header orientation |
| C1 | `WeatherBalloon:KEMET_C322C475K5R5TA` | Project THT footprint for selected radial 4.7 µF part |
| C2 | `WeatherBalloon:KEMET_C315C104K5R5TA` | Project THT footprint for selected radial 100 nF part |
| R1, R2, R4 | `Resistor_THT:R_Axial_DIN0207_L6.3mm_D2.5mm_P7.62mm_Horizontal` | Stock leaded axial footprint |
| D1 | `LED_THT:LED_D3.0mm` | Stock 3 mm leaded LED footprint |
| J5 | `Connector_JST:JST_XH_S2B-XH-A_1x02_P2.50mm_Horizontal` | Stock horizontal THT JST-XH; verify housing/contact/polarity |
| J2 | `Connector_PinHeader_2.54mm:PinHeader_1x09_P2.54mm_Vertical` | **Provisional:** electrical pin count/order known; physical pitch/position/drill unverified |
| J3 | `Connector_PinHeader_2.54mm:PinHeader_1x02_P2.54mm_Vertical` | **Provisional placeholder:** LightHAB pad pitch/position/drill unverified |

## Mechanical and artwork footprints

| Refs | Footprint | Status |
| --- | --- | --- |
| H1–H4 | `MountingHole:MountingHole_3.2mm_M3` | **Provisional:** 3.2 mm NPTH and all centers require measurement |
| G1 | `WeatherBalloon:CoffeeBalloon_7.5x11.25mm` | Padless front-silkscreen artwork; OUT1 and GND traces route outside its full envelope |

## Removed obsolete footprints

The following LightAPRS-era parts are absent from the board: SW1, U1, U2, Q1, C3, C4, C5, R3, J4, J6, and J7. J1 and A2 were subsequently removed when the logger supply moved to direct LightHAB 3V3. The carrier has no RF connectors, I2C expander, discrete cutdown driver, VBATT interface, or logger regulator.

## Fit-test hold

Do not fabricate this revision. The selected generic J2/J3 footprints and H1–H4 are deliberately visible placeholders, not claims that LightHAB uses 2.54 mm headers or 3.2 mm mounting holes. Replace them after measuring the purchased tracker, then perform a 1:1 paper fit with the actual module, headers/pins, standoffs, USB cable, SMA mates, batteries, OpenLog, JST cable, and enclosure.

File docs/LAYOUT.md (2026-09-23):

# Layout — provisional LightHAB carrier

The current PCB is a mechanically provisional, electrically complete LightHABTracker 1.0 carrier. It is suitable for reviewing architecture and ordering the already-verified carrier parts, but it is explicitly **not suitable for fabrication** until the purchased LightHAB is measured.

## Board and module zones

- Carrier outline: exactly 90 × 80 mm, from (100,90) to (190,170) mm.
- Provisional LightHAB envelope: 56 × 75 mm, from (134,95) to (190,170) mm.
- Mounting: LightHAB components face outward; the onboard 3×AA holder sits between the LightHAB and this carrier.
- Provisional board-to-board clearance: 18–20 mm.
- Carrier electronics: entirely in the left wing, outside the LightHAB body zone.
- OpenLog: top-left, with the microSD edge exposed toward the board top.
- LightHAB onboard SMA clearance: two mechanical-only bottom-edge reservations.
- LightHAB USB clearance: mechanical-only reservation at the right edge.

The module envelope, connector locations, and holes are photo-derived placeholders. Front silkscreen and User.Comments both state `UNVERIFIED LIGHTHAB FIT - DO NOT FABRICATE`.

## Placement

| Ref | Position / orientation | Purpose and status |
| --- | --- | --- |
| A1 | (116.5,110), 0° | Verified OpenLog module footprint; microSD accessible at top edge |
| R4 | (128,106), 180° | THT UART series resistor |
| C1 | (116,132), 0° | THT 4.7 µF logger bypass |
| C2 | (116,138), 0° | THT 100 nF logger bypass |
| R1 | (110,116), 0° | THT LED current resistor |
| D1 | (122.7,116), 180° | THT activity LED |
| R2 | (110,120), 0° | THT 100 kΩ LED reset pull-up |
| J5 | (108.5,158), 180° | Horizontal JST-XH cutdown output |
| J2 | (136.5,109), 0° | Provisional LightHAB 1×9 extended-pin interface |
| J3 | (144,155), 0° | Provisional LightHAB OUT1/GND interface |
| H1–H4 | (138,99), (186,99), (138,166), (186,166) | Provisional 3.2 mm NPTH module holes |
| G1 | (126,163), 0° | Front-silkscreen coffee-balloon artwork |

All populated electrical parts are direct-solder through-hole footprints. The four mounting holes are NPTH. G1 is artwork and has no pads.

## Routing

- Seven schematic nets are fully routed with zero unconnected pads.
- `GND` uses 0.8 mm B.Cu branches and a right-side return trunk.
- Direct `3V3` and `OUT1` use 0.5–0.8 mm copper; the OpenLog 3V3 branch runs on B.Cu and its local bypass branches run on F.Cu.
- UART and LED signals use 0.35 mm F.Cu.
- No carrier RF trace exists; both RF paths remain on LightHAB.
- The module zone contains only required mating-interface fanout and ground routing; no carrier component body is placed beneath it.

KiCad 10 reports zero DRC violations and zero unconnected items. The clean DRC proves internal CAD consistency, not LightHAB fit or pyro capability.

## Silkscreen and assembly readability

Front silkscreen labels identify OpenLog/microSD access, logger 3V3, activity, cutdown polarity, the extended-pin interface, OUT1/GND, and the no-fabrication warning. The warning sits above the module zone and remains visible with the module installed. The coffee-balloon artwork remains in the lower-left wing; the OUT1 and ground corridors route above and around its full silkscreen envelope.

Engineering annotations on User.Comments show the provisional LightHAB body, stack direction/clearance, SMA keepouts, and USB keepout. They are not copper or electrical pads.

## Required measurement update

Before a fit-test PCB, replace every provisional coordinate with measurements from the purchased LightHAB or an official dimensioned drawing:

1. Board outline and corner radii.
2. Four mounting-hole centers and finished hole diameters.
3. J2 pin pitch, row position, hole/drill size, and pin-1 orientation.
4. J3 OUT1/GND pad centers, drills, and polarity.
5. Battery-holder and maximum underside component height.
6. USB connector body and mating-cable envelope.
7. Both SMA body, nut, mating-connector, antenna/coax, and bend envelopes.
8. Onboard switch body/actuator envelope and battery-holder clearance.

After measurement, rerun the deterministic layout build, move only the provisional module interfaces/mechanics as required, reroute, regenerate a 1:1 PDF, and repeat ERC/DRC/no-SMD/visual checks.

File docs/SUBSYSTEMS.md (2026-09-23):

# Subsystems — Weather Balloon Logger carrier

The LightHABTracker 1.0 is the flight computer, GPS, radio system, battery carrier, logger power source, and pyro controller. This PCB is a passive through-hole carrier.

## Block diagram

```text
LightHAB 3×AA holder / onboard power
        +-- J2.3 3V3 --> OpenLog VCC + C1/C2 bypass
        +-- A1/PB08 --> 1 kΩ --> OpenLog RXI
        +-- A2/PB09 --> active-low activity LED
        +-- OUT1/GND --> J3 --> J5 JST-XH --> cutdown harness
        +-- onboard VHF/UHF radios --> onboard SMA connectors
```

LightHAB 3V3 current capacity and J3 OUT1 electrical capability are assumptions requiring bench validation.

## 1. Power

LightHAB J2.3 3V3 directly supplies OpenLog and its bypass capacitors. SparkFun supports a 3.3 V OpenLog supply; LightHAB rail capacity at startup/write current remains a bench-test gate.

## 2. Host / MCU

- J2: 1×9 extended-pin row ordered A1, A2, 3V3, GND, SCL, SDA, SCK, MISO, MOSI.
- J3: two-pin OUT1/GND pyro handoff to the carrier cutdown connector.
- A1 and A2 are the only extension GPIO used by the carrier.
- I2C and SPI contacts remain physically present and intentional no-connects.

The old LightAPRS 11-pin interface, separate VHF/HF contacts, carrier SMA connectors, carrier master switch, PCF8574 expander, and discrete cutdown driver are removed.

## 3.1 UART SD logger

LightHAB J2.3 directly powers OpenLog A1 VCC. C1 4.7 µF and C2 100 nF bypass the 3V3 rail at OpenLog. OpenLog remains a direct-solder module with through-hole headers.

LightHAB A1/PB08 provides one-way SERCOM4 TX. R4 1 kΩ limits possible back-power into A1 RXI during rail sequencing. OpenLog TXO, BLK, and GRN are intentionally unused.

## 4. UI (operator)

The tracker 3V3 rail drives R1 1 kΩ and D1. LightHAB A2/PB09 sinks `LED_N` when the LED should illuminate. R2 100 kΩ pulls `LED_N` high at reset so the LED defaults off. Firmware must set the output latch HIGH before configuring the pin as OUTPUT.

The PCF8574 and its decoupling capacitor are no longer present.

## 5. Cutdown

LightHAB OUT1/GND arrives at J3 and passes directly to J5, a horizontal JST-XH output. The carrier does not condition, amplify, switch, or fuse this path. Vendor documentation confirms two onboard pyro channels but does not publish sufficient electrical ratings for release. Bench characterization is mandatory before nichrome use.

The former TC4422, IRLZ44N, gate resistors, and bypass capacitors are removed. LightHAB firmware owns pyro default-off behavior and firing duration.

## 6. RF and mechanics

The carrier has no RF circuit. Both SMA connectors are part of LightHAB. The carrier only reserves physical keepouts for the SMA bodies, mating connectors, coax bends, USB access, battery holder, and module components.

The provisional layout mounts LightHAB on the right side, component face outward, with the battery holder between boards. Carrier electronics occupy the left wing. Photo-derived holes and pad positions are placeholders marked **UNVERIFIED — DO NOT FABRICATE** until measured on purchased hardware.

## 7. Intentional absences

| Block | Reason |
| --- | --- |
| Second MCU, GPS, radios | Integrated on LightHAB |
| Carrier battery holder/switch | LightHAB includes them |
| Carrier logger regulator | OpenLog accepts 3.3 V; LightHAB J2.3 supplies it directly |
| Carrier SMA and RF traces | LightHAB includes two SMA connectors |
| I2C LED expander | A2/PB09 directly drives one low-current LED |
| Carrier MOSFET/driver | LightHAB OUT1 is selected, pending rating verification |
| Host RX path | OpenLog is receive-only |
| Charger | Three primary L91 cells are used |

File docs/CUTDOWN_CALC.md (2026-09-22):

# Cutdown interface status

The earlier carrier MOSFET/driver calculation is obsolete. LightHABTracker 1.0 now owns cutdown switching and timing. The carrier only routes LightHAB OUT1/GND from J3 to the soldered JST-XH J5 connector.

No safe nichrome current, resistance, gauge, length, or pulse duration can be released from the present public information. Before connecting a burn wire:

1. obtain an authoritative LightHAB OUT1 voltage/current/duty rating or characterize it with a fuse, current-limited source, oscilloscope, and inert loads;
2. confirm which battery rail feeds OUT1 and its worst-case cold/end-of-discharge voltage;
3. measure connector, harness, and contact drop and temperature;
4. select nichrome resistance and pulse time within the verified envelope with margin;
5. use a mechanical crimp sleeve for nichrome-to-copper joining rather than relying on ordinary solder;
6. test reset, brownout, bootloader, and firmware failure cases before any live burn test.

Until those measurements exist, J5 is a provisional pass-through and not a qualified cutdown source.

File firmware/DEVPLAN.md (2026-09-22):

# LightHABTracker firmware integration plan

## Status and baseline

This repository contains a reviewed integration scaffold, not a compiled LightHAB flight image. Apply it to the official `lightaprs/LightHABTracker-1.0` source at inspected commit `797b78d120b0e844f60798b88dfa3735f27e89da`, then build and test with the project's actual Arduino SAMD board package. Re-check the upstream default branch before deliberately changing that pin.

The inspected source used D4/D5 for the two pyro channels and defaulted OUT1 cutdown duration to 10 seconds. A1/PB08 and A2/PB09 appeared unused, but this is an inspection result—not a guaranteed vendor interface contract.

## Pin contract

`docs/PINOUT.md` is authoritative. `tools/generate_pins.py` generates `include/pins.h` and stops if either required assignment changes:

- J2.1 A1/PB08: polling SERCOM4/PAD0 UART TX to OpenLog through R4.
- J2.2 A2/PB09: active-low activity LED. Write HIGH before `pinMode(..., OUTPUT)`.

No RX path is configured. SCL, SDA, SCK, MISO, and MOSI are not used by the carrier.

## Integration sequence

1. Check out the pinned upstream commit in a separate build tree and record the exact board package/tool versions.
2. Reconfirm A1/PB08 and A2/PB09 are unclaimed across source, variant files, and libraries.
3. Merge the OpenLog initialization and record-writing calls into the existing LightHAB setup/loop without replacing GPS, APRS, WSPR, telemetry, or vendor cutdown logic.
4. Initialize the LED HIGH-before-output before any potentially blocking work. Pulse it LOW only around attempted log writes.
5. Replace `telemetry_stub` with fields already produced by LightHAB. Keep buffers bounded and avoid heap allocation in the flight loop.
6. Build with warnings enabled and retain the complete build log and binary hash.

## Bench acceptance

1. Scope A2 through power-on, bootloader, reset, brownout, and firmware update; it must not glitch low before intended use.
2. Confirm A1/PB08 is SERCOM4/PAD0, idle-high, 3.3 V logic, 9600 baud 8-N-1 unless the installed OpenLog configuration is deliberately changed.
3. Confirm the header and one `0,0,0,READY` test row appear on a FAT32 microSD card. Verify the LED is off at reset/idle and pulses during the attempted write.
4. Repeat with the logger unplugged and its card missing/full/corrupt; GPS, APRS, WSPR, and LightHAB's own pyro logic must remain safe and responsive.
5. Verify both existing LightHAB OUT channels using inert dummy loads only. Do not infer pyro current capability from the carrier's direct pass-through.
6. Run a four-hour mission rehearsal at the intended battery, temperature, radio duty cycle, and logging interval, then validate the complete log.

## Release blockers

- Exact upstream build environment and successful compiled integration.
- Vendor or measured confirmation that A1/PB08 and A2/PB09 are safe to use.
- Installed OpenLog baud/current behavior and cold operation.
- Reset/brownout LED captures and logging fault-injection results.
- Independent validation of LightHAB OUT1 voltage/current capability and safety behavior.

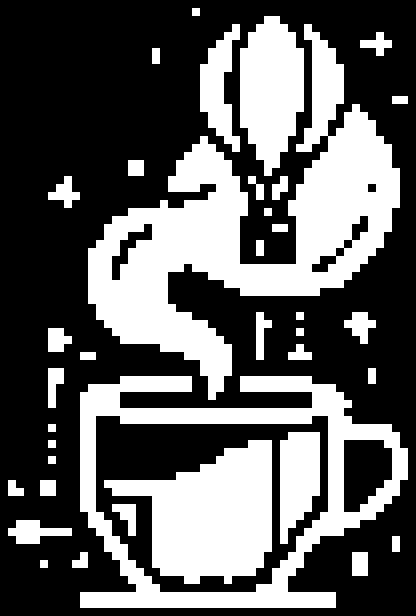
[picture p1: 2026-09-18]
assets/silkscreen/coffee-balloon-silkscreen.png

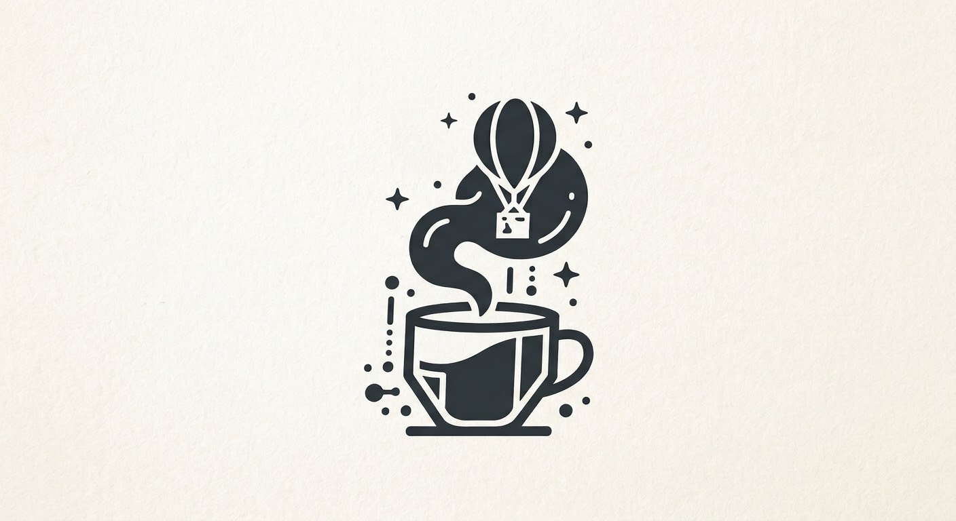
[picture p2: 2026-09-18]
assets/silkscreen/coffee-balloon-original.jpg

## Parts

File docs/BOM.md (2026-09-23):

# Bill of materials — Weather Balloon Logger harness

This is the complete carrier-PCB selection, re-audited on 2026-09-22. Exact
LightHAB mating parts remain intentionally TBD because the vendor has not
published sufficient pad and hole dimensions. Procurement and fabrication stay
on hold until purchased parts pass the documented fit, mating-part,
temperature, and electrical qualification checks.

## KiCad capture contract

No named LightHABTracker 1.0 or OpenLog symbol is available in the installed KiCad libraries, so the off-board modules are represented by installed generic connector symbols. J2 uses `Connector_Generic:Conn_01x09` in official known order A1, A2, 3V3, GND, SCL, SDA, SCK, MISO, MOSI. J3 uses `Connector_Generic:Conn_01x02` for the LightHAB OUT1/GND interface, and A1 remains the six-pin OpenLog connector. J2.1 A1/PB08 is UART_TX through R4; J2.2 A2/PB09 is active-low LED_N with R2=100 kΩ to 3V3 for reset-default-off; J2.3 directly powers OpenLog and C1/C2. J2.5–J2.9 are intentional no-connects. LightHAB 3V3 capacity is an accepted assumption requiring bench validation, and OUT1 pyro current capability remains explicitly unverified.

Installed-symbol pin contracts freshly confirmed on this machine:

- J3 and J5: `Connector_Generic:Conn_01x02`, package pins 1–2.
- J2: `Connector_Generic:Conn_01x09`, package pins 1–9 in A1, A2, 3V3, GND, SCL, SDA, SCK, MISO, MOSI order.
- A1: `Connector_Generic:Conn_01x06`, package pins 1–6.
- D1: `Device:LED`, pin 1 K and pin 2 A.
- R1, R2, and R4: `Device:R`, package pins 1–2. C1 and C2: `Device:C`, package pins 1–2.

## Fixed BOM

| Refdes | Value | Footprint | MPN | Rationale |
| --- | --- | --- | --- | --- |
| J2 | LightHABTracker 1.0 | Connector_PinHeader_2.54mm:PinHeader_1x09_P2.54mm_Vertical | TBD-LightHAB-1x9 | Provisional direct-solder through-hole 1x9 interface in official known order A1, A2, 3V3, GND, SCL, SDA, SCK, MISO, MOSI. Pin 1 is UART_TX; pin 2 is active-low LED_N; pins 5–9 are intentionally unconnected. Measure the purchased tracker and select the exact interface MPN before fabrication. |
| A1 | OpenLog | WeatherBalloon:SparkFun_OpenLog_DEV-13712_Carrier | DEV-13955 | SparkFun OpenLog with factory pre-soldered headers, mounted top-side with its straight header soldered directly into the carrier. Pin 1 = BLK, pin 2 = GND, pin 3 = VCC directly on LightHAB `3V3`, pin 4 = TXO, pin 5 = RXI, and pin 6 = GRN. SparkFun specifies 3.3–12 V VCC, recommends 3.3–5 V, and lists approximately 20–23 mA active writing current. LightHAB rail capacity requires bench validation. Source: https://learn.sparkfun.com/tutorials/openlog-hookup-guide/all |
| J3 | LightHAB OUT1/GND | Connector_PinHeader_2.54mm:PinHeader_1x02_P2.54mm_Vertical | TBD-LightHAB-OUT1 | Direct-solder through-hole two-pin LightHABTracker OUT1/GND pyro interface. It passes straight through to J5 with no carrier driver; LightHAB OUT1 polarity, switching behavior, and pyro current rating remain explicitly unverified. |
| J5 | Cutdown output | Connector_JST:JST_XH_S2B-XH-A_1x02_P2.50mm_Horizontal | S2B-XH-A(LF)(SN) | Retained direct-solder JST-XH cutdown output. Pin 1 receives LightHAB OUT1 directly from J3.1 and pin 2 is GND from J3.2; the carrier adds no pyro switch or current capability, and the LightHAB rating is unverified. |
| D1 | WP710A10SGC | LED_THT:LED_D3.0mm | WP710A10SGC | Kingbright 3 mm green leaded write-activity LED wired 3V3 → R1 → D1 anode, with D1 cathode on LightHAB A2/PB09 (`LED_N`). R2 holds the node high/off at reset. Verify polarity on the 1:1 print. |
| R1 | 1k | Resistor_THT:R_Axial_DIN0207_L6.3mm_D2.5mm_P7.62mm_Horizontal | MFR-25FBF52-1K | Yageo 1%, 1/4 W leaded metal-film LED current limiter; 6.3 x 2.4 mm nominal body on 7.62 mm pitch. |
| R4 | 1k | Resistor_THT:R_Axial_DIN0207_L6.3mm_D2.5mm_P7.62mm_Horizontal | MFR-25FBF52-1K | Same Yageo 1%, 1/4 W leaded metal-film part as R1, inserted through two 0.8 mm drilled holes on 7.62 mm pitch and soldered from the underside; no 0603 assembly. It limits possible UART back-power during rail sequencing or brownout. Verify UART signal integrity before release. |
| R2 | 100k | Resistor_THT:R_Axial_DIN0207_L6.3mm_D2.5mm_P7.62mm_Horizontal | MFR-25FBF52-100K | Yageo 1%, 1/4 W leaded metal-film pull-up from LED_N to 3V3. It keeps the active-low LED off while LightHAB A2/PB09 is high-impedance during reset. |
| C1 | 4.7uF | WeatherBalloon:KEMET_C322C475K5R5TA | C322C475K5R5TA | 50 V X7R radial ceramic OpenLog bulk bypass, 5.08 mm pitch, −55 to +125 °C. |
| C2 | 100nF | WeatherBalloon:KEMET_C315C104K5R5TA | C315C104K5R5TA | 50 V X7R radial ceramic OpenLog high-frequency bypass, 2.54 mm pitch, −55 to +125 °C. |

## Budget and intentional-absence notes

- The flight pack is exactly three Energizer L91 cells in the LightHAB holder. No carrier pack or switch is populated.
- J3 OUT1/GND passes directly to J5. The carrier does not add cutdown current capacity; LightHAB OUT1 ratings and behavior are release gates.
- OpenLog idle ≤7 mA and write ≤25 mA remain qualification targets. Confirm LightHAB 3V3 stays in tolerance during card inrush and writes.
- No relay, second MCU, carrier RTC, USB bridge, charger, carrier RF connector, I2C expander, or discrete cutdown driver is populated; each absence is intentional under SPEC.md.

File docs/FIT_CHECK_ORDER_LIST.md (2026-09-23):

# Physical fit-check order list

Prepared 2026-09-22 for the LightHABTracker carrier. The machine-readable version is `outputs/fit-check-order-list.xlsx`. Quantities under **Order** include practical spares.

## Buy now

| Category | Ref/use | Exact part | Need | Order | Source | Note |
| --- | --- | --- | ---: | ---: | --- | --- |
| Host module | Host | LightHABTracker 1.0 | 1 | 1 | [QRP Labs](https://shop.qrp-labs.com/aprs/LightHABTracker) | Measure before carrier fabrication. Includes the 3×AA holder. |
| Logger | A1 | SparkFun `DEV-13955` | 1 | 1 | [SparkFun](https://www.sparkfun.com/sparkfun-openlog-with-headers.html) | Buy the with-headers version. |
| Capacitor | C1 | KEMET `C322C475K5R5TA` | 1 | 3 | DigiKey | 4.7 µF radial THT. |
| Capacitor | C2 | KEMET `C315C104K5R5TA` | 1 | 5 | DigiKey | 100 nF radial THT. |
| LED | D1 | Kingbright `WP710A10SGC` | 1 | 2 | DigiKey | 3 mm green THT. |
| Connector | J5 | JST `S2B-XH-A(LF)(SN)` | 1 | 2 | DigiKey | Side-entry, two-position THT. |
| Resistor | R1, R4 | Yageo `MFR-25FBF52-1K` | 2 | 10 | DigiKey | 1 kΩ axial THT. |
| Resistor | R2 | Yageo `MFR-25FBF52-100K` | 1 | 5 | DigiKey | 100 kΩ axial THT pull-up. |
| J5 mate | Harness | JST `XHP-2` | 1 | 2 | DigiKey | Housing. |
| J5 leads | Harness | JST `ASXHSXH22K152` | 2 | 2 | DigiKey | 22 AWG pre-crimp leads; permanently mark polarity/function. |
| Cells | Flight/test | Energizer `L91` | 3 | 6 | Authorized retailer | Two matched 3-cell sets. |
| Storage | OpenLog | microSDHC ≤32 GB, FAT32 | 1 | 2 | Reputable retailer | One spare. |
| Fit tool | Mounting | M2/M2.5 nylon hardware assortment | 4 positions | 1 kit | Local supplier | Exact diameter/height waits for measurement. |

## Hold until the purchased LightHAB is measured

| Item | Reason | Closure |
| --- | --- | --- |
| J2 1×9 signal interface | Electrical order is known; mechanical location, pitch, and installed orientation are not authoritative. | Measure the actual row and select the exact direct-solder part. |
| J3 OUT1/GND interface | Pad geometry and output capability are unverified. | Measure it and qualify OUT1 with an inert load. |
| Bare carrier PCB | The provisional geometry is intentionally marked no-fabrication. | Update CAD from measurements and pass the 1:1 fit check. |
| APRS/WSPR antennas and cables | Bands, payload geometry, routing, and match are not released. | Select and test against the finished payload. |
| Nichrome and crimp sleeves | Resistance/current and joint sizes depend on verified OUT1 capability. | Qualify an inert load first, then cold-test the exact burn assembly. |
| Final mounting hardware | Hole diameter, stack height, underside components, holder, USB, and SMA envelopes are unknown. | Measure the complete tracker assembly. |

Do not buy the removed LightAPRS-era switch, carrier SMA connectors, RF pins, battery connector/holder, PCF8574, MOSFET driver, MOSFET, Pololu logger regulator, or their associated passives. They are not present in the LightHAB carrier.

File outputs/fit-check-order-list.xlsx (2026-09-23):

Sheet: Summary
Weather Balloon Logger - Fit-Check Order
Prepared | 2026-09-22
Scope | One complete carrier fit check plus practical prototype spares
Buy-now line items | 13
Held line items | 7
Required populated PCB refs | 10
Primary gate | Do not fabricate until the 1:1 exact-parts fit check passes
Ordering rules
1 | Buy exact MPNs for fit | Substitutes can change body, lead pitch, or connector envelope.
2 | Measure LightHAB first | J2/J3 and all four mounting holes remain provisional until the purchased tracker is measured.
3 | Use pre-crimp J5 leads | Avoids specialized JST production tooling for the prototype cutdown harness.
4 | Keep flight-critical holds | Interfaces, antennas, nichrome, sleeves, and final spacers need physical or test inputs.
5 | Recheck checkout | Stock, price, tariffs, and authorized-distributor status can change.

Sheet: Order List
Status | Category | Ref / Use | Manufacturer Part | Description | Need | Order | Source | Order / source link | Fit-check notes
BUY NOW | Module | A1 | DEV-13955 | SparkFun OpenLog with Headers | 1 | 1 | SparkFun | https://www.sparkfun.com/sparkfun-openlog-with-headers.html | Exact with-headers version
BUY NOW | Module | Host | LightHABTracker 1.0 | GPS/APRS/WSPR tracker with 3xAA holder and two pyro outputs | 1 | 1 | QRP Labs | https://shop.qrp-labs.com/aprs/LightHABTracker | Measure the purchased board before fabricating the carrier
BUY NOW | Capacitor | C1 | C322C475K5R5TA | 4.7 uF radial THT capacitor | 1 | 3 | DigiKey | https://www.digikey.com/en/products/result?keywords=C322C475K5R5TA | Prototype spares included
BUY NOW | Capacitor | C2 | C315C104K5R5TA | 0.1 uF radial THT capacitor | 1 | 5 | DigiKey | https://www.digikey.com/en/products/result?keywords=C315C104K5R5TA | Prototype spares included
BUY NOW | LED | D1 | WP710A10SGC | 3 mm green THT LED | 1 | 2 | DigiKey | https://www.digikey.com/en/products/result?keywords=WP710A10SGC
BUY NOW | PCB connector | J5 | S2B-XH-A(LF)(SN) | JST XH 2-pin side-entry THT header | 1 | 2 | DigiKey | https://www.digikey.com/en/products/result?keywords=S2B-XH-A%28LF%29%28SN%29 | Cutdown output
BUY NOW | Resistor | R1,R4 | MFR-25FBF52-1K | 1 kohm 1% 1/4 W axial | 2 | 10 | DigiKey | https://www.digikey.com/en/products/detail/yageo/MFR-25FBF52-1K/13011
BUY NOW | Resistor | R2 | MFR-25FBF52-100K | 100 kohm 1% 1/4 W axial | 1 | 5 | DigiKey | https://www.digikey.com/en/products/result?keywords=MFR-25FBF52-100K | LED reset-default-off pull-up
BUY NOW | Cutdown harness | J5 mate | XHP-2 | JST XH 2-position receptacle housing | 1 | 2 | DigiKey | https://www.digikey.com/en/products/result?keywords=XHP-2 | Housing only
BUY NOW | Cutdown harness | J5 leads | ASXHSXH22K152 | 22 AWG 6-inch pre-crimp socket-to-socket lead | 2 | 2 | DigiKey | https://www.digikey.com/en/products/detail/jst-sales-america-inc/ASXHSXH22K152/6684931 | Cut in half; identify OUT1 and GND
BUY NOW | Power | Flight/test cells | Energizer L91 | AA lithium primary cell | 3 | 6 | Authorized retailer | https://data.energizer.com/pdfs/l91.pdf | Two matched 3-cell sets
BUY NOW | Storage | OpenLog media | microSDHC <=32 GB | FAT32 microSD card | 1 | 2 | Reputable retailer | https://www.sparkfun.com/sparkfun-openlog-with-headers.html | One spare
BUY NOW | Mechanical fit tool | Module spacing | M2/M2.5 nylon hardware assortment | Spacers, screws, and nuts | 4 | 1 | Local supplier |  | Fit tool only; final diameter and height held
HOLD | Module interface | J2 | TBD after measurement | Nine-position signal solder interface | 1 | 0 | TBD |  | Verify actual row pitch, location, and installed header direction
HOLD | Module interface | J3 | TBD after measurement | Two-position OUT1/GND solder interface | 1 | 0 | TBD |  | Measure pad pitch, hole size, and mating method on LightHAB
HOLD | Fabrication | Carrier PCB | Bare PCB | Fabricated weather-balloon-logger carrier | 1 | 0 | PCB fabricator |  | Order only after exact-parts 1:1 fit gate passes
HOLD | RF system | Antennas/cables | TBD | APRS and WSPR antennas/cables for onboard SMA ports | 2 | 0 | TBD |  | Needs selected bands, payload geometry, cable length, and VSWR
HOLD | Cutdown | Burn element | TBD Nichrome 80 | Nichrome gauge and active length | 1 | 0 | TBD |  | Bench-select against verified LightHAB OUT1 rating and cold battery behavior
HOLD | Cutdown | Burn-wire joint | TBD crimp sleeve | Nichrome-to-copper mechanical splice | 2 | 0 | TBD |  | Size after wire selection; do not rely on solder
HOLD | Mechanical | Flight module spacers | TBD after measurement | Final LightHAB mounting hardware | 4 | 0 | TBD |  | Measure physical stack, holes, battery holder, USB, and SMA clearance first

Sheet: Hold Closure
Held item | Reason | Close the hold by | Release state
LightHAB J2/J3 interfaces | Vendor mechanical geometry is not published | Measure pitch, hole diameter, row location, orientation, and solder access on the purchased board | OPEN
LightHAB mounting holes | Provisional carrier coordinates are not authoritative | Measure all centers and diameters; update H1-H4 and the module outline | OPEN
Bare PCB fabrication | Measured-module fit gate precedes fabrication | Update CAD, print the 1:1 PDF, and verify all exact parts plus USB/SMA/battery clearances | OPEN
APRS/WSPR antennas and cables | Bands and payload geometry are not released | Select bands and enclosure layout; verify SMA mating, cable routing, match, and harmonics | OPEN
Nichrome wire | Gauge/length set resistance and current | Verify LightHAB OUT1 rating, then cold-test the selected wire and pulse duration | OPEN
Nichrome sleeves | Sleeve size follows final wire diameters | Choose compatible mechanical crimps; prove pull strength and contact heating | OPEN
Final mounting hardware | Physical module stack-up remains unmeasured | Measure hole diameter, board spacing, battery holder, USB, SMA, and underside clearance | OPEN
LightHAB 3V3/OUT1 behavior | 3V3 rail capacity and pyro current rating are unverified | Stress the 3V3 rail with OpenLog and radio activity; qualify OUT1 with an inert load before attaching nichrome | OPEN

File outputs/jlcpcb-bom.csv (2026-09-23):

Comment | Designator | Footprint | LCSC Part #
OpenLog | A1 | WeatherBalloon:SparkFun_OpenLog_DEV-13712_Carrier
4.7uF | C1 | WeatherBalloon:KEMET_C322C475K5R5TA
100nF | C2 | WeatherBalloon:KEMET_C315C104K5R5TA
WP710A10SGC | D1 | LED_THT:LED_D3.0mm
LightHABTracker 1.0 | J2 | Connector_PinHeader_2.54mm:PinHeader_1x09_P2.54mm_Vertical
LightHAB OUT1/GND | J3 | Connector_PinHeader_2.54mm:PinHeader_1x02_P2.54mm_Vertical
Cutdown output | J5 | Connector_JST:JST_XH_S2B-XH-A_1x02_P2.50mm_Horizontal
1k | R1,R4 | Resistor_THT:R_Axial_DIN0207_L6.3mm_D2.5mm_P7.62mm_Horizontal
100k | R2 | Resistor_THT:R_Axial_DIN0207_L6.3mm_D2.5mm_P7.62mm_Horizontal

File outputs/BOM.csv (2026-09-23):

refdes | MPN | qty
A1 | DEV-13955 | 1
C1 | C322C475K5R5TA | 1
C2 | C315C104K5R5TA | 1
D1 | WP710A10SGC | 1
J2 | TBD-LightHAB-1x9 | 1
J3 | TBD-LightHAB-OUT1 | 1
J5 | S2B-XH-A(LF)(SN) | 1
R1,R4 | MFR-25FBF52-1K | 2
R2 | MFR-25FBF52-100K | 1

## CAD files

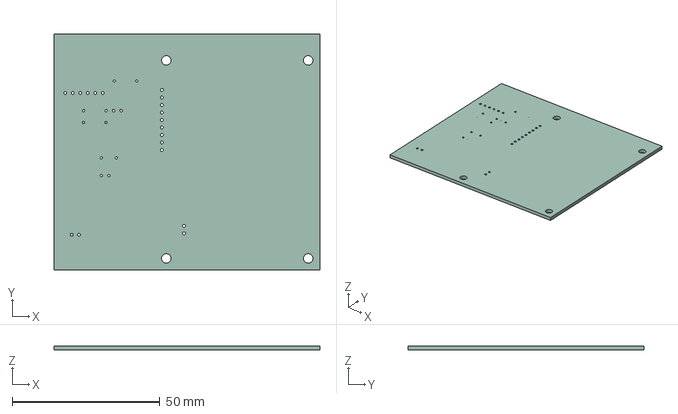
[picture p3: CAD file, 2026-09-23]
outputs/board.step
90.0 x 80.0 x 1.51 mm

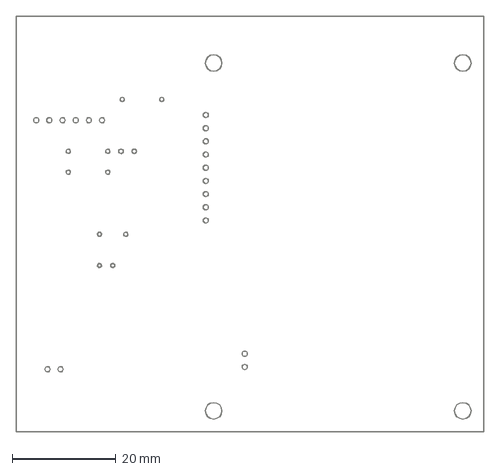
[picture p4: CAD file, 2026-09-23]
outputs/outline.dxf/weather-balloon-logger-Edge_Cuts.dxf
90.0 x 80.0 mm

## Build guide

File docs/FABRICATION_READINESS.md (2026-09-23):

# Fabrication readiness

Date: 2026-09-22

## Current disposition

**HOLD — DO NOT FABRICATE.**

The LightHAB carrier is electrically complete and clean: ERC, DRC, intent drift, and constraints pass; the PCB has zero unconnected items and zero SMD pads. The remaining blocker is mechanical truth. QRP Labs publishes the LightHABTracker overall size (56 × 75 mm), but the exact connector pad positions, mounting-hole coordinates/diameters, battery-holder stack height, USB clearance, and SMA clearance are not available in an authoritative dimensioned drawing.

The current board intentionally carries provisional J2/J3 and H1-H4 geometry plus a prominent `UNVERIFIED LIGHTHAB FIT - DO NOT FABRICATE` silkscreen warning. Generated Gerbers are review artifacts only.

## Minimum work before an engineering PCB order

- [ ] Buy the exact LightHABTracker 1.0 and the remaining buy-now parts in `FIT_CHECK_ORDER_LIST.md`.
- [ ] Measure the tracker with calipers: full outline, all four mounting holes, J2 nine-pin signal row, J3 OUT1/GND, component-side orientation, and pad/hole sizes.
- [ ] Measure maximum component height on both faces, installed 3×AA holder height, USB plug envelope, both SMA connector/cable envelopes, and required soldering access.
- [ ] Bench-confirm that J2.3 remains near 3.3 V during OpenLog startup and sustained writes, including radio transmit bursts and cold/end-of-discharge conditions.
- [ ] Obtain a vendor rating or safely measure LightHAB OUT1 voltage/current behavior with a fused inert load; do not connect nichrome yet.
- [ ] Update the PCB generator, footprint geometry, interface MPNs, BOM, and mechanical keepouts from those measurements.
- [ ] Regenerate the 1:1 fit-check PDF and physically place every exact part. Confirm 90.0 × 80.0 mm printed scale, lead entry, body clearances, solder access, USB/SMA access, and battery fit.
- [ ] Remove the no-fabrication warning only after the measurement record and physical fit check pass.
- [ ] Re-run ERC, DRC, Copperhead drift/constraints, through-hole audit, and independent Gerber review.
- [ ] Create a fabricator-specific ZIP containing only copper, mask, front silk, outline, and drill/job data; record board thickness, copper weight, finish, mask/silk colors, and electrical-test selection.

## Firmware gate

- [ ] Integrate the logger scaffold into official LightHABTracker source commit `797b78d120b0e844f60798b88dfa3735f27e89da` or deliberately document a newer reviewed baseline.
- [ ] Reconfirm A1/PB08 and A2/PB09 are unused, compile the exact target, and retain the build log/hash.
- [ ] Scope A2 through reset, bootloader, brownout, and update; the active-low LED must remain off until intentionally pulsed.
- [ ] Confirm OpenLog UART settings, current, real file writes, and fault behavior without disrupting GPS/APRS/WSPR or vendor pyro logic.

## Prototype qualification before any flight revision

- [ ] Verify 3S Energizer L91 operation, cold start, and four-hour energy margin with continuous GPS and representative radio/logging duty.
- [ ] Verify the direct LightHAB 3V3/OpenLog rail over the battery and temperature range; measure rail voltage, idle current, and write current.
- [ ] Test OUT1 only with inert dummy loads until its limits and safety behavior are established.
- [ ] Select nichrome gauge/length and mechanical crimp sleeves from the verified output envelope; qualify separation at cold/end-of-discharge conditions.
- [ ] Perform antenna/cable selection, match/harmonic checks, environmental testing, reset/brownout fault injection, and a complete four-hour mission rehearsal.

An engineering lot should remain small (five bare boards is sufficient): bring-up, logger integration, RF/payload fit, destructive/environmental test, and an untouched spare. Prototype success does not automatically make that revision a flight article.

## Release record

| Field | Value |
| --- | --- |
| Source commit/tag | |
| LightHAB measurement record | |
| Approved BOM revision | |
| Fabricator/stackup | |
| Gerber ZIP and SHA-256 | |
| ERC/DRC/drift/constraints | |
| 1:1 fit evidence | |
| Firmware build/hash | |
| Reviewer/date | |
| Disposition | HOLD / ENGINEERING PROTOTYPE / FLIGHT CANDIDATE |

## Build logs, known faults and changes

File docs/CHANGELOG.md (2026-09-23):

# Design changelog

Append-only, newest first. One entry per committed copperhead run.

## 2026-09-22 — Power OpenLog directly from LightHAB 3V3

- Removed the provisional J1 VBATT interface, A2 Pololu regulator, and the `VBATT`/`LOGGER_5V` nets from the live schematic and PCB.
- Connected LightHAB J2.3 3V3 directly to OpenLog A1 VCC, C1/C2 bypass, and the activity LED path; retained the 1 kΩ UART series resistor.
- Reduced the populated carrier BOM from 12 to 10 references and synchronized the order list, fit gates, layout/audit records, and review outputs.
- Kept LightHAB 3V3 capacity as an explicit bench-validation gate rather than treating the assumption as proven.

## 2026-09-22 — Clear the silkscreen logo

- Rerouted the OUT1 front-copper and J5 ground back-copper corridors above and around G1's complete 7.5 × 11.25 mm envelope.
- Preserved the logo position, electrical topology, 90 × 80 mm outline, LightHAB keepouts, and all-through-hole construction.

## 2026-09-21 — Complete the LightHABTracker migration

- Added controlled MPN fields to all 12 populated schematic symbols and regenerated BOM/order artifacts.
- Removed carrier cutdown control from the firmware scaffold; A2/PB09 now initializes HIGH-before-output as the active-low logger LED, while A1/PB08 remains OpenLog TX.
- Replaced stale LightAPRS procurement, readiness, cutdown, and development instructions with the measured-LightHAB fit gate.
- Regenerated schematic/PCB SVGs, green render, 1:1 PDF, Gerbers/drill, STEP, outline DXF, BOMs, and purchasing workbook.
- Verification: ERC clean; DRC clean with zero unconnected items; drift and constraints clean; 0 SMD pads; fabrication-source audit passed.

## 2026-09-17 — Export-only refresh from the current verified design. Do not modify schematic or PCB sources. Regenerate all existing output artifacts, including .copperhead/renders/board.svg, .copperhead/renders/weather-balloon-logger.svg, outputs/board.svg, outputs/renders/board-full-color.svg, outputs/renders/weather-balloon-logger.svg, all Gerbers and drill files in outputs/gerbers, outputs/board.step, the outline DXF, and BOM artifacts. Preserve the current verified through-hole design and readable silkscreen exactly.

- Change: refresh-all-verified-design-exports
- Files: outputs/
- Verification: ERC clean, DRC clean

## 2026-09-17 — Export-only refresh from the current verified design. Do not modify schematic, PCB, intent, libraries, constraints, firmware, BOM, or design docs. Regenerate .copperhead/renders/board.svg and weather-balloon-logger.svg plus outputs/board.svg, outputs/renders/weather-balloon-logger.svg, Gerbers, drill, STEP, outline DXF, and BOM artifacts from the current committed PCB/schematic state using deterministic export tools. Preserve the current zero-SMD all-through-hole design. Run ERC, DRC, drift, legibility, and constraints. Commit the already-synchronized documentation changes together with refreshed exports only if all checks are clean.

- Change: refresh-verified-design-exports
- Files: outputs/, weather-balloon-logger.svg
- Verification: ERC clean, DRC clean

## 2026-09-17 — Final PCB mechanical/legend cleanup. Current electrical DRC is clean with zero unconnected pads. Do not change schematic, intent, BOM, scripts, outline, RF routes, or functional topology. Fix the remaining 30 DRC findings only: move C4 and C5 to eliminate both J5 courtyard overlaps and three PTH-inside-courtyard errors, rerouting only their LOGGER_5V/GND connections while preserving electrical cleanliness; adjust F.SilkS geometry in both project KEMET footprint library files and their embedded C1-C5 board footprints so silk does not cross their own pad solder-mask openings; reposition or hide only reference text and local silk strokes causing the listed U1/R4, J5/C4/C5, U2/R3/Q1, and A2/U2 silk collisions. Preserve fabrication/fab/courtyard dimensions and all pads. Finish with normal KiCad DRC zero violations and zero unconnected items. Do not commit.

- Change: final-pcb-mechanical-legend-cleanup
- Files: library/WeatherBalloon.pretty/KEMET_C315C104K5R5TA.kicad_mod, library/WeatherBalloon.pretty/KEMET_C322C475K5R5TA.kicad_mod, weather-balloon-logger.kicad_pcb, docs\DECISIONS.md, docs/PINOUT.md
- Verification: ERC clean, DRC clean

## 2026-09-17 — Export-only refresh from the current committed design. Do not modify the schematic, PCB, schematic.intent.json, footprint libraries, constraints, firmware, BOM, or design documentation. Regenerate the current PCB SVG in .copperhead/renders and refresh outputs/board.svg using Copperhead's export_svg/export_outputs tools; bundled deterministic export artifacts may be refreshed as required by export_outputs. Preserve all existing fabrication qualification holds. Then run ERC, DRC, drift, schematic legibility, and constraint/spec validation. Finish only if the exports reflect the current weather-balloon-logger.kicad_pcb and checks are clean. Do not make layout or electrical changes.

- Change: refresh-current-pcb-exports
- Files: outputs/
- Verification: ERC clean, DRC clean

## 2026-09-17 — Replace R4 with leaded through-hole part

- Replaced R4's 0603 land pattern with `Resistor_THT:R_Axial_DIN0207_L6.3mm_D2.5mm_P7.62mm_Horizontal`.
- R4 now uses two 0.8 mm drilled holes, mounts horizontally at (166.62,118), and is soldered from the underside.
- Rerouted only local UART, GND, and I2C copper needed for the through-hole leads.
- Verification: normal KiCad DRC has zero violations and zero unconnected items; Copperhead ERC, DRC, drift, and constraints are clean.

## 2026-09-17 — Implement split-power PCB

- Placed direct-solder A2 at (106,121), 270°, and R4 at (159.8,113.3), 90°, without moving any existing footprint or changing the outline.
- Routed A2 VIN/SHDN directly from `PACK_SW`, GND to the pack return, and fixed `LOGGER_5V` to A1/C1/C2; the cutdown and LightAPRS feeds remain direct `PACK_SW` branches.
- Replaced the direct UART trace with `UART_TX` → R4 → `OPENLOG_RXI` and moved the board label to (110,96) for module access.
- Verification: normal KiCad DRC has zero violations and zero unconnected items; Copperhead ERC, DRC, drift, and constraints are clean.

## 2026-09-17 — Capture split-power schematic

- Added A2 Pololu S7V8F5 with SHDN/VIN on `PACK_SW`, GND common, and VOUT on new `LOGGER_5V`.
- Moved A1/C1/C2 from `3V3` to `LOGGER_5V` in the captured schematic.
- Added R4 1 kΩ between `UART_TX` and new `OPENLOG_RXI` to limit startup/brownout back-power.
- Preserved direct `PACK_SW` feeds to LightAPRS J2.1 and cutdown J5.1; PCB placement and routing remain the next bounded pass.
- Verification: Copperhead ERC, DRC, drift, and constraints clean; schematic legibility has zero errors and one unchanged low-utilization advisory.

## 2026-09-17 — Resume and complete the already proposed bounded add-pololu-s7v8f5-carrier-footprint pass. The exact new project-local footprint file WeatherBalloon:Pololu_S7V8F5_Carrier has now been created because the previous Copperhead run could not create a new KiCad file. Audit it against the validated OpenSpec proposal and official data: top-side direct-solder, 11.43 x 16.51 mm body, 1.02 mm official holes represented by 1.0 mm drills, 2.54 mm pitch, row centered and 1.27 mm from edge, top-view left-to-right pads 4 VOUT, 3 GND, 2 VIN, 1 SHDN. Make only necessary corrections to that footprint. Update library/README.md, docs/BOM.md, docs/FOOTPRINT_AUDIT.md, and this run's OpenSpec tasks to reserve A2 and correct C1/C2 future LOGGER_5V/current-limit prose. Do not modify schematic, PCB, schematic.intent.json, constraints, outputs, firmware, or historical proposals. Run ERC, DRC, drift, and commit this bounded footprint pass only if clean.

- Change: add-pololu-s7v8f5-carrier-footprint
- Files: library/README.md, docs/BOM.md, docs/FOOTPRINT_AUDIT.md, openspec/changes/add-pololu-s7v8f5-carrier-footprint/tasks.md
- Verification: ERC clean, DRC clean

## 2026-09-17 — Documentation and constraints pass only for the approved split-power architecture. Fixed battery is exactly 3 series Energizer L91 cells, 3.0-5.4 V. LightAPRS-W 2.0 RAW/J2.1 remains directly on switched PACK_SW so its GPS stays powered continuously for at least four hours. Cutdown J5.1 remains directly on PACK_SW and must never be routed through a regulator. Add Pololu S7V8F5 item 2123 as the selected dedicated fixed 5 V buck-boost module for OpenLog only: VIN and SHDN on PACK_SW, GND on GND, VOUT creates LOGGER_5V, and OpenLog A1 VCC moves from LightAPRS 3V3 to LOGGER_5V. Record input 2.7-11.8 V, fixed 5 V, <0.2 mA quiescent, 0.1-inch four-pin interface, direct-solder straight header, no reverse-polarity protection, and module temperature rating unverified requiring cold qualification. Update only current authoritative documentation, constraints, BOM, decisions/changelog, and this run's OpenSpec files; do not edit schematic, PCB, footprint libraries, outputs, firmware, or old historical proposals. Supersede stale 4S, 3V3-powered OpenLog, and 2 mA/1.85 mA limits in current docs. Use realistic limits of OpenLog idle <=7 mA, write <=25 mA, regulator Iq <=0.2 mA, board-added idle <=8 mA, and board-added active/write peak <=30 mA. Preserve existing PCF8574 and safety leakage limits. Keep the four-hour demand <=800 mAh and require >=1600 mAh usable capacity under actual cold/load profile. Run Copperhead checks and commit this bounded documentation pass only if consistent.

- Change: document-split-power-openlog-regulator
- Files: docs/SPEC.md, docs/SUBSYSTEMS.md, docs/BOM.md, docs/PINOUT.md, docs/DEVPLAN.md, docs/LAYOUT.md, docs/FOOTPRINT_AUDIT.md, docs/CHANGELOG.md, docs\DECISIONS.md, openspec/changes/document-split-power-openlog-regulator/tasks.md
- Verification: ERC clean, DRC clean

## 2026-09-16 — Document approved split-power OpenLog architecture

- Change: document-split-power-openlog-regulator
- Files: current authoritative docs, .copperhead/constraints.json, this run's OpenSpec files, docs/DECISIONS.md, docs/CHANGELOG.md
- Verification: documentation-only pass; fixed exactly 3s L91 at 3.0–5.4 V, preserved direct PACK_SW feeds to LightAPRS RAW/J2.1 and cutdown J5.1, selected Pololu S7V8F5 item 2123 for OpenLog-only LOGGER_5V, and superseded stale logger current budgets; schematic/PCB implementation intentionally deferred

## 2026-09-16 — SMA footprint/routing pass only. J3 and J4 now contain the exact KiCad footprints Connector_Coaxial:SMA_Amphenol_132134_Vertical, each with center pad 1 and four through-hole shield pads numbered 2. Their current positions are J3 (168,162) for RF_APRS and J4 (112,162) for RF_WSPR and must remain fixed; the footprints fit the outline and existing RF reservation.\n\nRepair only this real-footprint fallout:\n- Keep all footprints, orientations, and board edges fixed.\n- Preserve J6 RF_APRS to J3 center pad 1 and J7 RF_WSPR to J4 center pad 1.\n- Reroute only RF_APRS, RF_WSPR, and local GND so neither center conductor crosses or violates clearance to any shield pad.\n- Connect all four pad-2 shield tabs on each SMA solidly to GND using short symmetric local copper and/or nearby ground vias/trunk connections appropriate for a first-pass RF launch.\n- Remove dangling placeholder ground stubs.\n- Preserve the existing >=5 mm RF/mechanical reservation drawings and keep unrelated copper/components out.\n- Do not claim final 50-ohm qualification: document that trace geometry and return-via strategy still require released stackup calculation and VNA validation.\n- Preserve all six exact LightAPRS mechanical-interface exclusions; add no global DRC suppression.\n- Update docs/LAYOUT.md and docs/FOOTPRINT_AUDIT.md with the actual SMA pad/fanout result and remaining RF fabrication hold.\n- Run normal kicad-cli DRC and Copperhead checks. Commit this pass only with zero normal DRC violations and zero unconnected items.

- Change: repair-sma-footprint-routing
- Files: weather-balloon-logger.kicad_pcb, docs/LAYOUT.md, docs/FOOTPRINT_AUDIT.md, docs/CHANGELOG.md, docs\DECISIONS.md
- Verification: ERC clean, DRC clean

## 2026-09-16 — Repair exact SMA launch routing

- Change: repair-sma-footprint-routing
- Files: weather-balloon-logger.kicad_pcb, docs/LAYOUT.md, docs/FOOTPRINT_AUDIT.md, docs/CHANGELOG.md, docs/DECISIONS.md
- Verification: exact fixed J3/J4 footprints retain J6→J3.1 RF_APRS and J7→J4.1 RF_WSPR; all eight pad-2 shield tabs connect through symmetric local B.Cu fanouts to the bottom GND trunk; normal DRC clean with zero violations and zero unconnected items; 50 Ω stackup calculation, final return-via design, and VNA validation remain fabrication holds

## 2026-09-16 — OpenLog mechanical pass only. A1 now contains the exact project footprint WeatherBalloon:SparkFun_OpenLog_DEV-13712_Carrier with the official 15.24 x 19.05 mm module body/courtyard and solder-down header. The real body currently extends above the draft board outline, and only two stale routes plus two A1 edge-silk findings remain.\n\nMake the smallest coherent OpenLog layout change:\n- Keep the exact A1 footprint identity, pad geometry, top-side installation, and direct-solder assembly.\n- Keep the LightAPRS module interface J2/J6/J7/H1-H4 and its 32.77 x 54.80 mm reserved body coordinates fixed.\n- Keep all footprints fixed except A1, C1, and C2. You may move/rotate only those three to create a practical OpenLog cluster outside the LightAPRS body zone.\n- Enlarge the board outline only as much as needed to fully contain A1's courtyard and allow practical access to the OpenLog microSD card and header for home assembly. Prefer extending the top/right edges rather than disturbing the fixed module and bottom RF layout.\n- Keep A1 pin order BLK through GRN and preserve nets: pad 2 GND, pad 3 3V3, pad 5 UART_TX; unused module pins remain intentionally unconnected as captured.\n- Reroute only A1/C1/C2-related GND, 3V3, and UART_TX copper. Remove stale route ends and keep bypass capacitors reasonably close to A1's supply pins.\n- Keep every other footprint and route unchanged except an unavoidable ground/power trunk extension.\n- Preserve the six exact documented LightAPRS interface exclusions and do not add global DRC suppression.\n- Resolve all DRC/connectivity/silkscreen/edge findings and update docs/LAYOUT.md and docs/FOOTPRINT_AUDIT.md with the final outline and A1/C1/C2 coordinates plus access rationale.\n- Run normal kicad-cli DRC and Copperhead checks. Commit only with zero normal DRC violations and zero unconnected items.

- Change: repair-openlog-mechanical-layout
- Files: docs/LAYOUT.md, docs/FOOTPRINT_AUDIT.md, docs\DECISIONS.md, weather-balloon-logger.kicad_pcb, docs/CHANGELOG.md
- Verification: ERC clean, DRC clean

## 2026-09-16 — Repair exact OpenLog mechanical layout

- Change: repair-openlog-mechanical-layout
- Files: weather-balloon-logger.kicad_pcb, docs/LAYOUT.md, docs/FOOTPRINT_AUDIT.md, docs/CHANGELOG.md, docs/DECISIONS.md
- Verification: normal DRC clean with zero violations and zero unconnected items; ERC clean; drift clean; schematic legibility has zero errors and one unchanged low-utilization advisory; A1 is at (171,110), C1/C2 remain at (168,114)/(164,114), and only the top outline edge extends to y=91.5 mm

## 2026-09-16 — Power connector pass only. J1, J5, and SW1 now contain their exact real footprints: Connector_JST:JST_PH_S2B-PH-K_1x02_P2.00mm_Horizontal, Connector_JST:JST_XH_S2B-XH-A_1x02_P2.50mm_Horizontal, and WeatherBalloon:SW_CK_7101SYZQE. SW1 is the requested C&K 7101SYZQE with direct-solder plated slots; keep its library identity and pad geometry.\n\nRepair this batch in the smallest manufacturable change:\n- Keep the board outline and every footprint except J1, J5, and SW1 fixed.\n- You may move and rotate only J1, J5, and SW1 so their real bodies/courtyards do not overlap, remain fully inside the board, and their mating/actuation directions remain accessible from board edges for hand assembly.\n- Preserve net intent: SW1 pad 2 is PACK_IN common, pad 1 is switched PACK_SW, and pad 3 is intentionally no-connect. Never connect pad 3.\n- Reroute only PACK_IN, PACK_SW, GND, and CUTDOWN_OUT as locally necessary; remove stale track segments beneath the real switch/connector bodies.\n- Maintain existing current-capable track widths for the battery and cutdown paths.\n- Resolve all new courtyard, edge, silkscreen, solder-mask, short, and connectivity findings without global DRC suppression. Reference-text or nonfunctional silk may move/hide.\n- Preserve the six already documented and exact vendor-module exclusions in weather-balloon-logger.kicad_pro.\n- Update docs/FOOTPRINT_AUDIT.md with final J1/J5/SW1 locations/orientations and hand-assembly accessibility.\n- Run kicad-cli DRC and Copperhead checks. Commit this bounded pass only if normal DRC has zero violations and zero unconnected items.

- Change: repair-power-connector-footprints
- Files: weather-balloon-logger.kicad_pcb, docs/LAYOUT.md, docs/FOOTPRINT_AUDIT.md, docs/CHANGELOG.md, docs\DECISIONS.md
- Verification: ERC clean, DRC clean

## 2026-09-16 — Repair real power connector placement

- Change: repair-power-connector-footprints
- Files: weather-balloon-logger.kicad_pcb, docs/FOOTPRINT_AUDIT.md, docs/LAYOUT.md, docs/CHANGELOG.md, docs/DECISIONS.md
- Verification: normal DRC clean with zero violations and zero unconnected items; ERC clean; drift clean; J1/J5 remain at their edge-accessible real-footprint positions, only SW1 moves to (114,108), local PACK_IN/PACK_SW/GND/CUTDOWN_DRAIN copper is repaired, pad 3 remains unconnected, and all six vendor-module exclusions are preserved

## 2026-09-16 — Add front-silkscreen (F.SilkS) board label text reading 'JAVAS Logger' in a clear, readable area that does not overlap any component, pad, trace, mounting hole (H1-H4), the 32.77 x 54.80 mm module zone, or the >=5 mm SMA keepouts. Use a standard silkscreen text height of about 1.5-2 mm, horizontal and right-reading (upright). A good open area is the left-center of the board. Update docs/LAYOUT.md to note the label, then re-run DRC and keep it clean.

- Change: add-javas-logger-silkscreen-label
- Files: weather-balloon-logger.kicad_pcb, docs/LAYOUT.md, docs/CHANGELOG.md, docs\DECISIONS.md
- Verification: ERC clean, DRC clean

## 2026-09-16 — Add front-silkscreen `JAVAS Logger` board label

- Change: add-javas-logger-silkscreen-label
- Files: weather-balloon-logger.kicad_pcb, docs/LAYOUT.md, docs/CHANGELOG.md, docs/DECISIONS.md
- Verification: label centered at (114.5, 118.0) mm on F.SilkS with 1.8 mm upright text; DRC and drift re-run

## 2026-09-16 — Apply the measured LightAPRS-W 2.0 coordinates from docs/SUBSYSTEMS.md section 6 (Measured coordinate transcription) to the board. (1) Place the four module standoff holes as ~M2 (2.2 mm) holes at H1 (125.9,115.35), H2 (154.1,115.35), H3 (125.9,153.52), H4 (154.1,153.52), forming a 28.18 x 38.16 mm rectangle. (2) Keep J2 (11-pin, 2.548 mm pitch, 270 deg) along the right edge at about x=154.9, centered vertically over the rectangular body, spanning about y=121.7 to 147.2. (3) Keep J7 HF at the module bottom-left and J6 VHF at the module bottom-right, positioned clear of the H3/H4 standoff holes. (4) Keep every other component outside the 32.77 x 54.80 mm module zone and honor the >=5 mm SMA keepouts. Update docs/LAYOUT.md and re-run DRC; iterate placement and routing until DRC is clean.

- Change: apply-measured-lightaprs-module-coordinates
- Files: weather-balloon-logger.kicad_pcb, docs/LAYOUT.md, docs\DECISIONS.md
- Verification: ERC clean, DRC clean

## 2026-09-16 — Correct the module-mount layout to the exact verified LightAPRS-W 2.0 geometry and FACE-UP orientation in docs/SUBSYSTEMS.md section 6. (1) Resize the module-mount zone to exactly 32.77 x 54.80 mm with the long axis vertical. (2) The module mounts FACE UP, so carrier pads must match the module top view with NO left-right mirror: place J2 (11-pin header) on the zone edge that matches the module's header edge, and place the RF corner contacts as HF bottom-left = J7 and VHF bottom-right = J6, which reverses the previous mirrored placement. (3) Keep RF nets VHF/J6 -> J3 (RF_APRS) and HF/J7 -> J4 (RF_WSPR); the two SMA jacks are edge-mounted facing down, so move J3 toward the VHF/right side and J4 toward the HF/left side for short launches. (4) Place four approximate M2 standoff holes on the dimensioned pattern with about a 42.73 mm outer horizontal span. (5) Keep J1, SW1, A1, U1, C3, Q1 and all passives outside the module zone and honor the >=5 mm SMA keepouts. Update docs/LAYOUT.md and the board, then re-run DRC.

- Change: correct-face-up-lightaprs-module-layout
- Files: weather-balloon-logger.kicad_pcb, docs/LAYOUT.md, docs\DECISIONS.md
- Verification: ERC clean, DRC clean

## 2026-09-16 — Re-lay-out the board for the revised schematic and reserve a 32 x 55 mm LightAPRS-W 2.0 module-mount zone per docs/SUBSYSTEMS.md section 6. Place the mating headers J2 (11-pin host interface), J6 (VHF) and J7 (HF) INSIDE that zone, positioned to align with the module's 2.54 mm edge header and its bottom opposite-corner HF/VHF pins so the module plugs directly onto them; add corner standoff mounting holes in the zone. Place all OTHER components (J1 pack input, SW1, A1 OpenLog, U1 PCF8574T + C3, J3/J4 SMA jacks, Q1 cutdown plus D1/R1/R2/R3/C1/C2) OUTSIDE the module footprint so they cannot collide with the module body, honoring the >=5 mm SMA keepouts. Update docs/LAYOUT.md and the board, then re-run DRC.

- Change: relayout-revised-lightaprs-module-zone
- Files: weather-balloon-logger.kicad_pcb, docs/LAYOUT.md, docs/SUBSYSTEMS.md, docs/CHANGELOG.md, docs\DECISIONS.md
- Verification: ERC clean, DRC clean

## 2026-09-16 — Re-layout revised LightAPRS module zone

- Change: relayout-revised-lightaprs-module-zone
- Files: weather-balloon-logger.kicad_pcb, docs/LAYOUT.md, docs/SUBSYSTEMS.md, docs/CHANGELOG.md, docs/DECISIONS.md, .copperhead/constraints.json
- Verification: revised 18-refdes board synchronized to the schematic; 32 × 55 mm module zone with J2/J6/J7 and four approximate standoff holes; all other components outside; separate SMA envelopes retained; DRC clean; fabrication remains blocked on exact module geometry, footprints, RF, thermal, and part qualification

## 2026-09-16 — Revise the host interface and add an I2C LED expander to match the verified LightAPRS-W 2.0 module (docs/SUBSYSTEMS.md section 6). Final pin plan: A1/PB08 = OpenLog UART TX one-way (host TX to OpenLog RXI, no host RX); A2/PB09 = cutdown gate on a direct GPIO (keep R2 series gate resistor and R3 gate pulldown for default-off at power-up); write LED and future GPS-status LEDs on a PCF8574 I2C GPIO expander. (1) Change J2 to the module's 11-position 2.54mm edge header using an installed 11-pin connector symbol Connector_Generic:Conn_01x11, pin order RAW, GND, A1(PB08), A2(PB09), 3V3, GND, SCL, SDA, SCK, MISO, MOSI; wire PACK_SW switched pack+ to RAW, board 3V3 rail from 3V3, GND to the GND pins, A1 to OpenLog RXI, A2 to the cutdown gate network. (2) Add a PCF8574 I2C GPIO expander using an installed KiCad symbol powered from 3V3/GND with a 100nF decoupling cap, address pins strapped for 0x20, SDA/SCL on the module's exposed I2C bus; drive write LED D1 active-low from output P0 (expander output to D1 cathode, D1 anode to 3V3 via R1); leave P1..P7 available for future GPS-satellite-status LEDs as no-connect. (3) Move the cutdown gate source from A0 to A2/PB09, keeping the intentional pulldown so it is default-off. (4) Represent RF as two single contacts HF and VHF at the module opposite bottom corners: VHF to J3 (RF_APRS), HF to J4 (RF_WSPR); replace the 2-pin J6 with the two corner contacts. (5) Update docs/PINOUT.md, docs/BOM.md, docs/SUBSYSTEMS.md and the schematic; keep 3.3V logic and all leakage/idle budgets. Run ERC.

- Change: revise-lightaprs-host-and-i2c-led-expander
- Files: schematic.intent.json, docs/BOM.md, docs/PINOUT.md, docs/SUBSYSTEMS.md, weather-balloon-logger.kicad_sch, docs/SPEC.md, firmware/tools/generate_pins.py, firmware/include/pins.h, firmware/include/cutdown.h, firmware/README.md, firmware/DEVPLAN.md, docs/DEVPLAN.md, docs/LAYOUT.md, docs/CHANGELOG.md, docs\DECISIONS.md
- Verification: ERC clean, DRC clean

## 2026-09-16 — revise verified LightAPRS interface and LED expansion

- Change: revise-lightaprs-host-and-i2c-led-expander
- Files: schematic.intent.json, weather-balloon-logger.kicad_sch, docs/BOM.md, docs/PINOUT.md, docs/SPEC.md, docs/SUBSYSTEMS.md, docs/DEVPLAN.md, docs/LAYOUT.md, firmware pin-contract docs/files, .copperhead/constraints.json, docs/DECISIONS.md
- Verification: ERC clean; drift clean; schematic legibility 0 errors with one low-utilization advisory; DRC clean on the unchanged but explicitly obsolete PCB; installed functional symbols and PCF8574T pins verified; engine-local copperhead_power helpers remain intentionally exempt; existing PCB/outputs remain blocked pending layout synchronization

## 2026-09-16 — create pipeline stage: devplan

- Change: devplan-weather-balloon-logger
- Files: docs/DEVPLAN.md, docs/CHANGELOG.md, docs\DECISIONS.md
- Verification: ERC clean, DRC clean

## 2026-09-16 — create pipeline stage: devplan

- Change: devplan-weather-balloon-logger
- Files: docs/DEVPLAN.md, docs/CHANGELOG.md, docs/DECISIONS.md
- Verification: hardware bring-up, probe-location, risk, and prototype-order plan added; ERC, DRC, drift, and schematic legibility checks run in this stage

## 2026-09-16 — create pipeline stage: firmware

- Change: firmware-weather-balloon-logger
- Files: firmware/tools/generate_pins.py, firmware/include/pins.h, firmware/include/cutdown.h, firmware/include/openlog.h, firmware/include/telemetry.h, firmware/src/cutdown.cpp, firmware/src/openlog.cpp, firmware/src/telemetry_stub.cpp, firmware/WeatherBalloonLogger.ino, firmware/README.md, firmware/DEVPLAN.md, docs/CHANGELOG.md, docs\DECISIONS.md, openspec/changes/firmware-weather-balloon-logger/tasks.md
- Verification: ERC clean, DRC clean

## 2026-09-16 — create pipeline stage: firmware

- Change: firmware-weather-balloon-logger
- Files: firmware/, docs/CHANGELOG.md, docs/DECISIONS.md, .copperhead/constraints.json
- Verification: pins generated from docs/PINOUT.md; safe one-record happy path added; C++11 compatibility/readback checks clean; firmware not compiled here because no exact board package/compiler/build action is exposed; ERC clean; DRC clean; drift clean; schematic legibility 0 errors with one low-utilization advisory

## 2026-09-16 — create pipeline stage: outputs

- Change: outputs-weather-balloon-logger
- Files: outputs/, outputs/BOM.csv, outputs/README.md, docs\DECISIONS.md, docs/CHANGELOG.md
- Verification: ERC clean, DRC clean

## 2026-09-16 — create pipeline stage: outputs

- Change: outputs-weather-balloon-logger
- Files: outputs/ Gerbers and drill, outputs/outline.dxf, outputs/board.step, outputs/board.svg, outputs/schematic.svg, outputs/BOM.csv, outputs/README.md, docs/CHANGELOG.md, docs/DECISIONS.md
- Verification: every requested export succeeded; ERC clean; DRC clean; drift clean; schematic legibility 0 errors with one low-utilization advisory; output package remains explicitly blocked from fabrication and procurement because CopperheadDraft footprints and all MPNs are UNVERIFIED

## 2026-09-16 — create pipeline stage: layout-draft

- Change: layout-draft-weather-balloon-logger
- Files: docs\DECISIONS.md
- Verification: ERC clean, DRC clean

## 2026-09-16 — create pipeline stage: layout-draft

- Change: layout-draft-weather-balloon-logger
- Files: docs\DECISIONS.md
- Verification: ERC clean, DRC clean

## 2026-09-16 — create pipeline stage: layout-draft

- Change: layout-draft-weather-balloon-logger
- Files: weather-balloon-logger.kicad_pcb, LAYOUT.md, docs/CHANGELOG.md, docs\DECISIONS.md
- Verification: ERC clean, DRC clean

## 2026-09-16 — create pipeline stage: layout-draft

- Change: layout-draft-weather-balloon-logger
- Files: weather-balloon-logger.kicad_pcb, LAYOUT.md, docs/CHANGELOG.md, docs/DECISIONS.md
- Verification: 80 × 70 mm coordinate-level board draft; all 15 refdes placed; critical power, ground, RF, decoupling, UART/LED, and cutdown nets routed; dual SMA clearance envelopes and ESD reservation areas documented; DRC clean; board SVG exported; board-local draft land patterns explicitly require verified-footprint replacement before fabrication

## 2026-09-16 — create pipeline stage: schematic

- Change: schematic-weather-balloon-logger
- Files: schematic.intent.json, weather-balloon-logger.kicad_sch, docs/BOM.md, docs/SPEC.md, docs/SUBSYSTEMS.md, docs/PINOUT.md, docs/CHANGELOG.md, docs\DECISIONS.md
- Verification: ERC clean

## 2026-09-15 — create pipeline stage: schematic

- Change: schematic-weather-balloon-logger
- Files: schematic.intent.json, weather-balloon-logger.kicad_sch, docs/PINOUT.md, docs/BOM.md, docs/SPEC.md, docs/SUBSYSTEMS.md, docs/CHANGELOG.md, docs/DECISIONS.md, .copperhead/constraints.json
- Verification: deterministic draft with 15 BOM parts and six subsystem groups; all BOM symbol pins confirmed; ERC clean; legibility 0 errors with one low-utilization advisory; BOM/PINOUT drift clean; generated copperhead_power rail helpers reconciled as engine-local symbols

## 2026-09-15 — create pipeline stage: part-selection

- Change: recover-part-selection-weather-balloon-logger
- Files: docs/BOM.md, docs/CHANGELOG.md, docs\DECISIONS.md
- Verification: ERC not required

## 2026-09-15 — recover pipeline stage: part-selection

- Change: recover-part-selection-weather-balloon-logger
- Files: docs/BOM.md, docs/CHANGELOG.md, docs/DECISIONS.md
- Verification: complete BOM reread; fresh installed-symbol searches and authoritative pin checks; power-budget audit; check_drift after readback

## 2026-09-15 — create pipeline stage: part-selection

- Change: part-selection-weather-balloon-logger
- Files: docs/BOM.md, docs/CHANGELOG.md, docs\DECISIONS.md
- Verification: ERC not required

## 2026-09-15 — recover pipeline stage: part-selection

- Change: part-selection-weather-balloon-logger
- Files: docs/BOM.md, docs/CHANGELOG.md, docs/DECISIONS.md
- Verification: exact five-column/one-refdes BOM read back; named-module absence and all selected installed symbols/pins tool-verified; constraint revisits resolved; check_drift run before finish

## 2026-09-15 — create pipeline stage: part-selection

- Change: part-selection-weather-balloon-logger
- Files: docs/BOM.md, docs/CHANGELOG.md, docs\DECISIONS.md
- Verification: ERC not required

## 2026-09-15 — create pipeline stage: part-selection

- Change: part-selection-weather-balloon-logger
- Files: docs/BOM.md, docs/CHANGELOG.md, docs/DECISIONS.md
- Verification: installed KiCad symbols searched and authoritative pins checked; BOM-to-schematic drift checked before finish

## 2026-09-15 — create pipeline stage: architecture

- Change: architecture-weather-balloon-logger
- Files: docs/SUBSYSTEMS.md, docs/CHANGELOG.md, docs\DECISIONS.md
- Verification: ERC not required

## 2026-09-15 — create pipeline stage: architecture

- Change: architecture-weather-balloon-logger
- Files: docs/SUBSYSTEMS.md, docs/CHANGELOG.md, docs/DECISIONS.md
- Verification: ERC not required (no schematic this stage)

## 2026-09-15 — create pipeline stage: spec-seed

- Change: seed-weather-balloon-logger-spec
- Files: docs/SPEC.md, docs\DECISIONS.md
- Verification: ERC not required
# 2026-09-21 — provisional LightHAB PCB rebuild

- Replaced the obsolete LightAPRS layout with the 12-reference LightHAB electrical design.
- Added a 90 × 80 mm outline, provisional 56 × 75 mm module zone, four provisional 3.2 mm NPTH holes, onboard SMA/USB mechanical keepouts, functional silkscreen labels, and a prominent no-fabrication warning.
- Preserved the coffee-balloon front-silkscreen artwork and moved all populated carrier parts to the left wing.
- Verification: KiCad ERC clean; DRC clean; zero unconnected items; zero SMD pads; Copperhead drift/constraints/legibility checks clean except the existing A4 paper-size advisory.

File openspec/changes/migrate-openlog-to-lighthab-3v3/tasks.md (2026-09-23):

# Tasks

- [x] Inspect the current intent and exact schematic s-expressions.
- [x] Surgically remove J1/A2 and the VBATT/LOGGER_5V connectivity from intent and schematic.
- [x] Reconnect the five specified supply pins to 3V3 without changing other nets or component choices.
- [x] Update docs/BOM.md, docs/SPEC.md, docs/SUBSYSTEMS.md, docs/PINOUT.md, and the affected constraint records with one-line rationales and the bench-validation hold.
- [x] Remove J1/A2 from the PCB and route direct 3V3 to A1/C1/C2 without disturbing UART, LED, cutdown, logo, or module keepouts.
- [x] Synchronize BOM/order/readiness/audit records and regenerate all tracked review and manufacturing outputs.
- [x] Verify ERC, DRC, zero unconnected pads, zero SMD pads, schematic legibility, drift, constraints, workbook rendering, and the fabrication-source audit.
- [x] Confirm firmware is unchanged and retain the explicit no-fabrication hold for provisional LightHAB mechanics and 3V3 capacity.

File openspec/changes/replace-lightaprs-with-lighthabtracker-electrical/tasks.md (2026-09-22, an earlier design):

# Tasks

- [x] Inspect current intent, schematic symbols/nets, and authoritative installed symbol pins.
- [x] Validate this bounded electrical-only proposal before editing.
- [x] Surgically update intent and schematic with exact refdes, pin order, nets, footprints, and intentional no-connects.
- [x] Update authoritative electrical documentation and constraints; record one-line rationale for each non-trivial decision and each intentional removal.
- [x] Verify all retained/new symbols against installed KiCad libraries.
- [x] Run ERC and repair every violation.
- [x] Run schematic legibility and reconcile every error-severity finding.
- [x] Run drift/intent consistency checks and resolve stale electrical references in the scoped docs.
- [x] Finish only when the bounded schematic pass is clean, while explicitly leaving PCB/layout/output synchronization for the later pass requested by the user.

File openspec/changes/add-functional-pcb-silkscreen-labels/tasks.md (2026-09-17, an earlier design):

# Tasks

- [ ] Inspect the current PCB text, component geometry, and available silkscreen areas.
- [ ] Add BATTERY IN and polarity labels at J1; MASTER POWER at SW1; 5V REGULATOR at A2; OPENLOG at A1; LIGHTAPRS-W 2.0 in a safe central-module identification area; HOST HEADER at J2; LED EXPANDER at U1; CUTDOWN DRIVER at U2; CUTDOWN LOAD plus PACK+ and FET- at J5; CUTDOWN FET at Q1; WRITE LED at D1; VHF and HF at J6 and J7; and APRS SMA and WSPR SMA at J3 and J4.
- [ ] Confirm by readback that only F.SilkS graphics or text and docs/LAYOUT.md changed.
- [ ] Run normal DRC and require zero violations and zero unconnected pads.
- [ ] Run ERC, schematic legibility, drift, and required constraint checks.
- [ ] Record the labeling rationale and finish without committing.

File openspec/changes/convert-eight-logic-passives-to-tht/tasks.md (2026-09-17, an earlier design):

# Tasks

- [ ] Verify the installed PCF8574P symbol and its pin contract against the current U1 contract.
- [ ] Read the exact intent and schematic text needed for surgical edits.
- [ ] Update the eight existing references in schematic.intent.json and weather-balloon-logger.kicad_sch without changing connectivity.
- [ ] Update BOM, footprint audit, and directly necessary current documentation; record PCB conversion as pending.
- [ ] Verify symbols and reconcile all findings.
- [ ] Run ERC and require a clean result.
- [ ] Run schematic legibility and reconcile every error-severity finding.
- [ ] Run intent/BOM/PINOUT drift checks and require a clean result.
- [ ] Run DRC to confirm the intentionally untouched existing PCB remains clean.
- [ ] Finish only after all checks pass.

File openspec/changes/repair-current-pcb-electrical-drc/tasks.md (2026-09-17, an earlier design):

# Tasks

- [ ] Read the current PCB text and current DRC report to identify exact segments and unique edit anchors.
- [ ] Delete obsolete stubs and repair only local electrical copper.
- [ ] Re-run DRC and iterate until electrical categories and unconnected count are zero.
- [ ] Run required ERC, schematic legibility, and drift checks to confirm the PCB-only repair introduced no cross-artifact regression.
- [ ] Finish without committing.

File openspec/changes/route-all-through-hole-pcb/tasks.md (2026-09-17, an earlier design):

# Tasks

- [ ] Inspect the current PCB footprints, pads, nets, tracks, vias, keepouts, and fixed geometry.
- [ ] Identify and remove only obsolete SMD-era tracks and vias in the affected local areas.
- [ ] Route all affected and new through-hole component pads with the required minimum widths and no net-name changes.
- [ ] Confirm the board contains zero SMD component pads and zero unconnected items.
- [ ] Run normal KiCad DRC and iteratively correct every violation without global suppression.
- [ ] Run ERC, schematic legibility, and drift checks to prove the PCB-only pass did not disturb authoritative design data.
- [ ] Finish without committing.

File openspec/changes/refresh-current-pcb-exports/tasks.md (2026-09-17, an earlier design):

# Tasks

- [ ] Validate this export-only proposal.
- [ ] Export the current PCB SVG to `.copperhead/renders/`.
- [ ] Refresh `outputs/board.svg` and permitted deterministic bundled outputs using the export tool when available.
- [ ] Run ERC and DRC.
- [ ] Run schematic legibility, drift, and constraint/spec validation.
- [ ] Confirm exports derive from the current committed PCB and finish only when all checks are clean.

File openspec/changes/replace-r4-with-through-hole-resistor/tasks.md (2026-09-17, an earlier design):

# Tasks

- [x] Change R4's intent and schematic footprint to the stock DIN0207 axial through-hole footprint.
- [x] Replace the PCB land pattern and place it clear of A1/C1/C2/U1 and the LightAPRS body zone.
- [x] Reroute local UART, GND, and I2C copper around the drilled pads.
- [x] Update BOM, layout, footprint audit, decisions, and changelog.
- [x] Run normal DRC to zero violations and zero unconnected items plus Copperhead ERC, drift, legibility, and constraints checks.

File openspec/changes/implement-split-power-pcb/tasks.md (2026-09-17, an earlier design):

# Tasks

- [x] Read the current PCB text and identify exact A1/C1/C2 UART/power copper, placement openings, keepouts, exclusions, and unique edit anchors.
- [x] Add and place A2/R4 without moving existing footprints; move only the nonfunctional board label if strictly necessary.
- [x] Remove stale OpenLog 3V3/direct-UART copper and route PACK_SW, GND, LOGGER_5V, UART_TX, and OPENLOG_RXI with practical widths and short loops.
- [x] Confirm J2.1 and J5.1 remain directly on PACK_SW and no cutdown path passes through A2.
- [x] Update layout/audit/decision/changelog/OpenSpec documentation with one-line rationales and actual coordinates/routing.
- [x] Run normal DRC to zero violations and zero unconnected items; run ERC, schematic legibility, drift, and all Copperhead completion checks.
- [x] Commit/finish only when schematic, PCB, BOM, and docs agree.

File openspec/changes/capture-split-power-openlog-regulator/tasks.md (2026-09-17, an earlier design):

# Tasks

- [x] Read the current schematic and intent anchors and confirm installed connector/resistor pin contracts.
- [x] Add and group A2 in Power and R4 in UART SD logger without disturbing existing interfaces or no-connects.
- [x] Rewire the OpenLog supply/bypass nodes to `LOGGER_5V` and its receive input to `OPENLOG_RXI`.
- [x] Synchronize BOM, PINOUT, SPEC/SUBSYSTEMS/DEVPLAN/LAYOUT/FOOTPRINT_AUDIT as applicable, CHANGELOG, DECISIONS, and this run's OpenSpec tasks while truthfully deferring PCB work.
- [x] Verify symbols, run ERC, schematic legibility/score, unchanged-board DRC, and drift; reconcile every blocking finding.
- [x] Finish only when electrical checks are clean and the PCB deferral is explicit.

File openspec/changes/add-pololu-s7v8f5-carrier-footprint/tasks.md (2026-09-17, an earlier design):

# Tasks

- [x] Inspect the existing footprint-library conventions and audit the supplied S7V8F5 footprint.
- [x] Make only necessary footprint corrections for official geometry, pad order, annular rings, courtyard, and direct-solder/top-side markings. No footprint edit was necessary: the supplied file already matches the validated geometry and markings.
- [x] Update only the three authorized documentation files with future A2 assignment and corrected C1/C2 LOGGER_5V/current-limit language.
- [x] Update and read back this run's task checklist and every changed file.
- [x] Run ERC, DRC, drift, and applicable Copperhead checks; ERC, DRC, and drift are clean.

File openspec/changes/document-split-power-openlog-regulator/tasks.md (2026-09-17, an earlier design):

# Tasks

- [x] Inventory stale architecture and budget references in current authoritative docs/constraints and identify this run’s OpenSpec files.
- [x] Update SPEC, SUBSYSTEMS, BOM, PINOUT/DEVPLAN/LAYOUT/FOOTPRINT_AUDIT only where current statements are affected.
- [x] Update the constraint registry for exact 3S voltage/cell count, split logger rail, regulator limits, OpenLog operating currents, and board-added idle/active budgets while preserving safety constraints.
- [x] Record the approved decision and append a changelog entry with one-line rationale for each non-trivial choice.
- [x] Update only this run’s OpenSpec proposal/task files; leave historical proposals untouched.
- [x] Run ERC, DRC, drift, and documentation consistency checks; finish only if the bounded pass is consistent.

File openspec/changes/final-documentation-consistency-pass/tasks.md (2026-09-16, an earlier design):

# Tasks

- [x] Confirm no CopperheadDraft occurrences remain in the PCB and verify J2's actual board orientation.
- [x] Surgically correct docs/LAYOUT.md and docs/FOOTPRINT_AUDIT.md only.
- [x] Read back the corrected documentation and confirm stale claims are gone.
- [x] Run ERC, DRC, schematic legibility, drift, and final Copperhead obligation checks.
- [x] Commit only the bounded documentation corrections if all checks are clean.

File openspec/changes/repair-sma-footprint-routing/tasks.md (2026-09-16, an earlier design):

# Tasks

- [ ] Read the exact J3/J4 footprint, pad, segment, via, zone, reservation, and exclusion anchors from the PCB source.
- [ ] Surgically replace only the affected RF_APRS, RF_WSPR, and local GND routing.
- [ ] Confirm all eight SMA shield pads are connected and both RF centers retain the required J6/J7 mappings.
- [ ] Update layout/audit/decision/changelog documentation with one-line rationales and the remaining RF qualification hold.
- [ ] Run normal DRC to zero violations and zero unconnected items, then ERC, schematic legibility, drift, and final Copperhead checks.

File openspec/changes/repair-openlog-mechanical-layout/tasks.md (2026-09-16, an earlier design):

# Tasks

- [ ] Read the actual PCB anchors and baseline normal DRC report.
- [ ] Select the smallest top/right outline extension and A1/C1/C2 placement that contains the real courtyard and preserves access.
- [ ] Surgically edit the PCB placement, outline, local silk, and only A1-related GND/3V3/UART_TX copper.
- [ ] Verify A1 pads 2/3/5 remain GND/3V3/UART_TX and unused pins remain unconnected.
- [ ] Update layout, footprint-audit, decision, and changelog documentation.
- [ ] Run normal DRC to zero violations and zero unconnected items; run ERC, schematic legibility, drift, and Copperhead verification checks.
- [ ] Reconcile every blocking finding and finish only when all gates pass.

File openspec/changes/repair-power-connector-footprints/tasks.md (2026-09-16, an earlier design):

# Tasks

- [ ] Read the actual PCB/project anchors and confirm J1/J5/SW1 pads, positions, orientations, affected nets, and existing exclusions.
- [ ] Reposition only J1/J5/SW1 and surgically replace only stale local power/cutdown routing.
- [ ] Verify SW1 pad 3 remains unconnected and current-path widths are maintained.
- [ ] Update docs/FOOTPRINT_AUDIT.md plus decision/changelog rationale.
- [ ] Run normal DRC to zero violations and zero unconnected items, then run ERC, drift, and other Copperhead verification gates.
- [ ] Finish only after all bounded-pass obligations are clean.

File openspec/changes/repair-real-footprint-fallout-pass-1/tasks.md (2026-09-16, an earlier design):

# Tasks

- [ ] Read the current PCB anchors, import script, audit, and baseline DRC report.
- [ ] Repair Q1 pad 1 CUTDOWN_GATE and pad 2 GND routing with no shorts, hole-clearance, or solder-mask errors.
- [ ] Adjust only necessary routing/vias near U1 pads 4 and 15.
- [ ] Add narrowly scoped H3/J7 and H4/J6 courtyard exclusions and document why the physical vendor features are valid despite stock courtyard overlap.
- [ ] Resolve A1/C1 reference-text overlap and J6 silk-over-hole warnings without moving footprints.
- [ ] Run DRC/connectivity, inspect every remaining finding, and iterate to zero unsuppressed errors.
- [ ] Run ERC and drift checks, record decisions, update changelog/audit, and commit the bounded pass if the available workflow exposes commit support.

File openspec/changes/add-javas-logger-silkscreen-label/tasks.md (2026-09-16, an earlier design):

# Tasks

- [ ] Inspect the actual PCB text and geometry for a unique edit anchor and clear left-center location.
- [ ] Insert the F.SilkS text without overlapping components, pads, traces, H1-H4, the LightAPRS module zone, or SMA keepouts.
- [ ] Update docs/LAYOUT.md with a one-line placement rationale.
- [ ] Run DRC, inspect any violations, and resolve them.
- [ ] Run drift checks and finish only after verification passes.

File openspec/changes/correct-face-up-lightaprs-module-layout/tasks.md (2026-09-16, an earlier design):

# Tasks

- [ ] Read the existing PCB s-expressions and identify unique anchors for the module zone, J2/J6/J7, J3/J4, mounting holes, keepout drawings, and affected routing.
- [ ] Surgically edit the board placement, graphics, and affected traces without regenerating the file.
- [ ] Update docs/LAYOUT.md with exact FACE-UP coordinates, corrected RF-side mapping, standoff approximation, keepouts, and remaining fabrication holds.
- [ ] Record the mechanical/layout decision and revised constraint.
- [ ] Run DRC, inspect and fix every violation, then run drift checks and finish only when clean.

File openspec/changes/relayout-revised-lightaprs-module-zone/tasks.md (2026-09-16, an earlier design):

# Tasks

- [ ] Read the existing PCB and identify unique surgical-edit anchors.
- [ ] Confirm revised schematic refdes/nets and board synchronization requirements.
- [ ] Replace obsolete board placement/connectivity with the revised component set and module zone.
- [ ] Add four non-plated corner standoff holes within the module zone without conflicting with mating contacts.
- [ ] Route all revised nets and preserve power, leakage, cutdown, RF, and keepout constraints.
- [ ] Update layout documentation and record the mechanical/layout decisions.
- [ ] Run DRC, inspect every violation, repair and rerun until clean.
- [ ] Run drift checks and finish only after documentation and PCB are synchronized.

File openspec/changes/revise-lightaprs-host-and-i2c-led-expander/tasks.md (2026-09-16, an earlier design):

# Tasks

- [ ] Read the current schematic and locate every stale interface/pin/RF/LED reference.
- [ ] Verify installed 11-pin, one-pin, and PCF8574 symbols and authoritative pin contracts.
- [ ] Surgically edit the schematic with consistent refdes and net names.
- [ ] Update BOM and design/firmware documentation, recording the revised host-pin and expander decisions and constraints.
- [ ] Verify symbols, run ERC, reconcile schematic legibility findings, and run drift checks.
- [ ] Run PCB DRC or explicitly reconcile PCB/layout impact from the changed host interface before finishing.

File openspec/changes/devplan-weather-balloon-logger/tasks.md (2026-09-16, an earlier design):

# Tasks

- [ ] Read any existing hardware and firmware development-plan material and preserve their distinct scopes.
- [ ] Write `docs/DEVPLAN.md` with prerequisites, instruments, ordered bring-up, test locations, first-meter checks, stop conditions, risk register, and prototype order gates.
- [ ] Use exact schematic net names and refdes; do not invent uncaptured test-point components.
- [ ] Keep every CopperheadDraft footprint and BOM MPN explicitly UNVERIFIED and block fabrication/procurement until the relevant acceptance checks pass.
- [ ] Append the Stage 8 entry to `docs/CHANGELOG.md` and record the development-plan decision in `docs/DECISIONS.md`.
- [ ] Run ERC, DRC, drift, and schematic legibility checks to confirm documentation work did not desynchronize or disturb the design.
- [ ] Finish only after all verification obligations pass.

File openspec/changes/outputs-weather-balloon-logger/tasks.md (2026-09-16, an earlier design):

# Tasks

- [ ] Validate this change proposal.
- [ ] Preflight the schematic, PCB, BOM, and output directory.
- [ ] Run ERC and DRC and reconcile any violations.
- [ ] Export JLC Gerbers and drill files; verify every required file exists and is non-empty.
- [ ] Export outline DXF and STEP; verify both exports succeed and are non-empty.
- [ ] Run `export_svg` for schematic and PCB and include both renders in `outputs/`.
- [ ] Generate and read back `outputs/BOM.csv` with columns `refdes,MPN,qty`, consolidating identical MPNs without dropping UNVERIFIED markers.
- [ ] Record the Stage 6 packaging decision and append the changelog entry.
- [ ] Run legibility, drift, ERC, and DRC final checks; finish only after all exports and gates pass.

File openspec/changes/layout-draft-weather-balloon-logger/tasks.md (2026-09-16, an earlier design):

# Tasks

- [ ] Read back the exact existing board and layout documentation.
- [ ] Validate placement, routing, keepouts, footprints, and net names against SPEC/BOM/PINOUT.
- [ ] Apply only necessary surgical edits to the PCB and documentation.
- [ ] Run DRC and resolve every violation.
- [ ] Export the PCB SVG and verify its exact path.
- [ ] Run drift checks and update decisions/changelog as needed.
- [ ] Invoke artifact registration for the exact `.kicad_pcb`, `LAYOUT.md`, and exported PCB SVG paths, then verify registration before finish.

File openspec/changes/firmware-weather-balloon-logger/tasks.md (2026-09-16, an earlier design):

# Tasks

- [x] Inspect existing project conventions and any firmware/build files.
- [x] Create the minimal firmware directory and ATSAMD21G18 HAL/build scaffold.
- [x] Derive `pins.h` solely from `docs/PINOUT.md`, with source and safety comments.
- [x] Implement driver stubs and the safe logging happy path.
- [x] Attempt the vendor build when available; otherwise document `not compiled here` explicitly in `firmware/DEVPLAN.md`.
- [x] Record the firmware architecture and default-off decision in design docs.
- [x] Run ERC, DRC, drift, and applicable consistency checks; reconcile every blocking result.
- [x] Finish only after all required verification gates pass.

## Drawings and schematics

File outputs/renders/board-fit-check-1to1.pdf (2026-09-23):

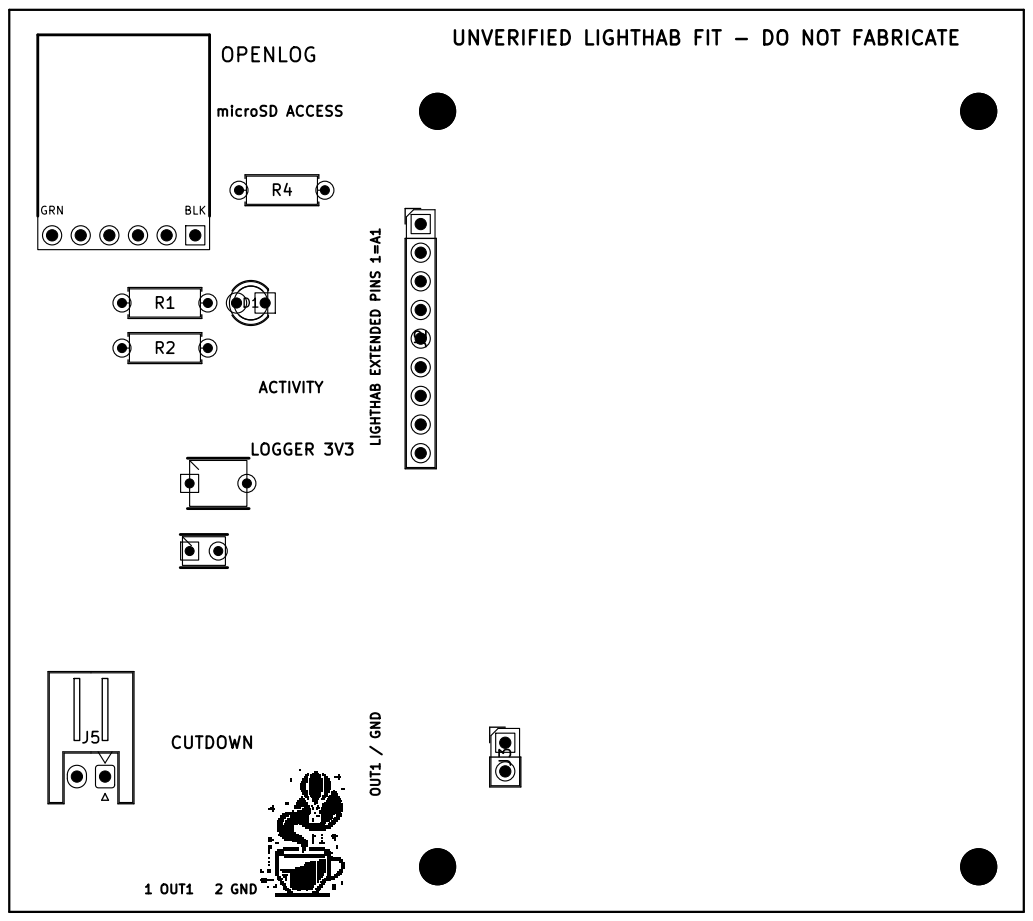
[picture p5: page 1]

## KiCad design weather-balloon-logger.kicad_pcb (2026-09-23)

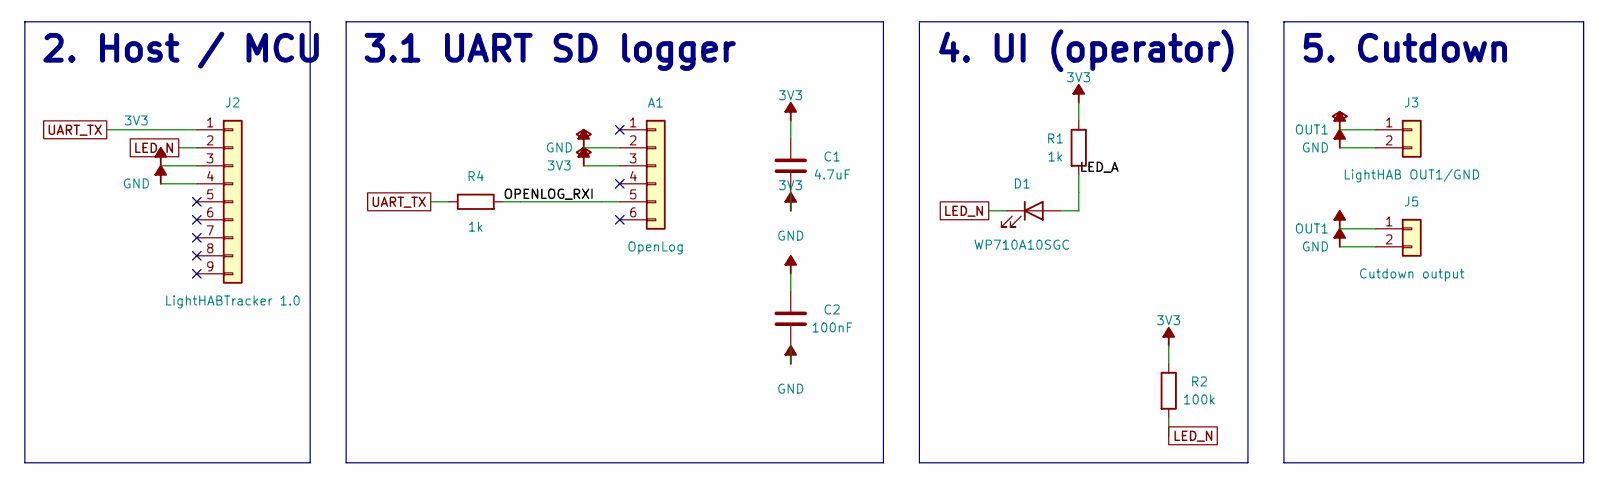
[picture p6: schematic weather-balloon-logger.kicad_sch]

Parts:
A1: OpenLog; SparkFun_OpenLog_DEV-13712_Carrier; MPN DEV-13955
C1: 4.7uF; KEMET_C322C475K5R5TA; MPN C322C475K5R5TA
C2: 100nF; KEMET_C315C104K5R5TA; MPN C315C104K5R5TA
D1: WP710A10SGC; LED_D3.0mm; MPN WP710A10SGC
J2: LightHABTracker 1.0; PinHeader_1x09_P2.54mm_Vertical; MPN TBD-LightHAB-1x9
J3: LightHAB OUT1/GND; PinHeader_1x02_P2.54mm_Vertical; MPN TBD-LightHAB-OUT1
J5: Cutdown output; JST_XH_S2B-XH-A_1x02_P2.50mm_Horizontal; MPN S2B-XH-A(LF)(SN)
R1, R4: 1k; R_Axial_DIN0207_L6.3mm_D2.5mm_P7.62mm_Horizontal; MPN MFR-25FBF52-1K
R2: 100k; R_Axial_DIN0207_L6.3mm_D2.5mm_P7.62mm_Horizontal; MPN MFR-25FBF52-100K

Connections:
3V3: A1.3, C1.1, C2.1, J2.3, R1.1, R2.1
GND: A1.2, C1.2, C2.2, J2.4, J3.2, J5.2
LED_A: D1.2 (A), R1.2
LED_N: D1.1 (K), J2.2, R2.2
OPENLOG_RXI: A1.5, R4.2
OUT1: J3.1, J5.1
UART_TX: J2.1, R4.1

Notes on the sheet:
2. Host / MCU
3.1 UART SD logger
4. UI (operator)
5. Cutdown

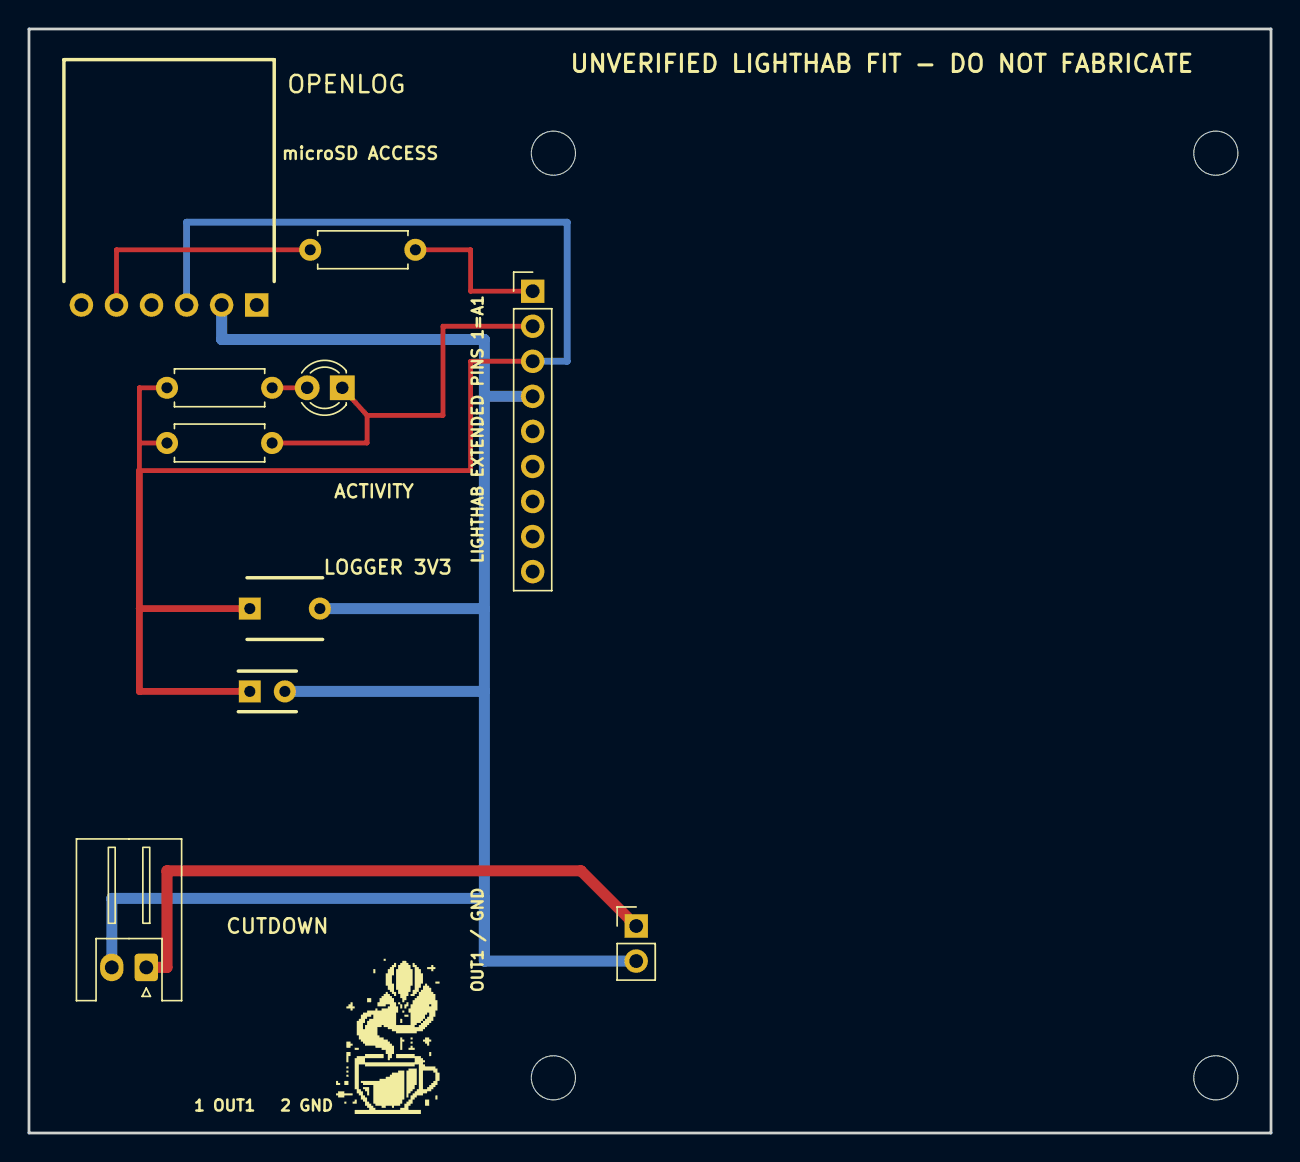
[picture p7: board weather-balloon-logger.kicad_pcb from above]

Board: 2 copper layers, 90.0 x 80.0 mm, 15 parts (0 on the bottom side), 7 nets.

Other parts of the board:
G1: Coffee Balloon; CoffeeBalloon_7.5x11.25mm
H1, H2, H3, H4: LIGHTHAB HOLE - UNVERIFIED; MountingHole_3.2mm_M3

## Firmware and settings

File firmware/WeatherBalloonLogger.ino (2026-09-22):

#include "include/openlog.h"
#include "include/pins.h"
#include "include/telemetry.h"

namespace {
bool sample_written = false;
}

void setup() {
  // A2/PB09 is active-low. Preload HIGH before enabling the output so reset
  // and initialization cannot flash the activity LED.
  digitalWrite(weather_balloon::pins::kActivityLed, HIGH);
  pinMode(weather_balloon::pins::kActivityLed, OUTPUT);

  if (!weather_balloon::openlog::init(weather_balloon::pins::kOpenLogBaud)) {
    return;
  }

  char record[48];
  if (weather_balloon::telemetry::format_sample(record, sizeof(record))) {
    digitalWrite(weather_balloon::pins::kActivityLed, LOW);
    weather_balloon::openlog::write_line("sequence,gps_fix,altitude_m,logger");
    weather_balloon::openlog::write_line(record);
    digitalWrite(weather_balloon::pins::kActivityLed, HIGH);
    sample_written = true;
  }
}

void loop() {
  // The scaffold writes exactly one deterministic record. Production firmware
  // will schedule samples here. LightHAB's own upstream firmware retains sole
  // ownership of its OUT1 cutdown behavior.
  if (sample_written) {
    __WFI();
  }
}

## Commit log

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2026-09-15 copperhead: create pipeline stage: spec-seed
    Seeded docs/SPEC.md for the Weather Balloon Logger (LightAPRS-W 2.0 harness: L91 pack+switch, dual downward SMA, OpenLog+write LED, nichrome cutdown). Recorded all budgets including ASSUMED numbers (4 h, 3–4s L91, 3.0–7.2 V, ≤200 mA mean, ≥1600 mAh usable, Iq/leakage, 3.3 V GPIO, OpenLog VCC, SMA keepout, cutdown 2 A and 3.3 V Vgs — IRLZ44N not auto-approved). Intentional absences: no carrier MCU/RTC/charger/USB-UART. openspec/ not seeded. No schematic this stage.
    Verification: ERC not required
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2026-09-15 copperhead: create pipeline stage: architecture
    Architecture stage complete: docs/SUBSYSTEMS.md freezes the harness block diagram against SPEC budgets (3s L91 / 4s only if UVLO, SW1 breaks pack+, 3V3 fan-out, OpenLog UART, dual downward 50 Ω SMA, 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
2026-09-15 copperhead: create pipeline stage: part-selection
    Created pipeline stage part-selection: added docs/BOM.md with one row per refdes and exact Value-field discipline; selected installed KiCad symbols and confirmed their real pins; documented generic connector proxies for unavailable LightAPRS-W/OpenLog named symbols; selected AO3400A with 3.3 V gate-drive, leakage, SOA, and thermal acceptance checks; marked every MPN UNVERIFIED; checked all parts against switch-off, board-idle, LED-off, cutdown leakage/current, temperature, RF, and pack constraints; updated changelog and decisions; check_drift is clean with no schematic configured. OpenLog release remains conditional on a verified maximum idle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
2026-09-15 copperhead: create pipeline stage: part-selection
    Completed stage 3 part selection. docs/BOM.md was read back in full with the exact Refdes/Value/Footprint/MPN/Rationale format and one row per refdes; D1 was normalized to component-only Value LTST-C190KGKT. All MPNs remain UNVERIFIED with datasheet-verifiable electrical, footprint, temperature, leakage/Iq, and pin/order checks. Named LightAPRS-W 2.0 and OpenLog symbols were confirmed absent, so their off-board interfaces use installed generic connector symbols; every selected connector, switch, coax, MOSFET, LED, resistor, and capacitor symbol has authoritative package pins recorded. All reopened BOM constraint revisits were resolved, the de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
2026-09-15 copperhead: create pipeline stage: part-selection
    Recovered and completed stage-3 part selection. docs/BOM.md has the exact five-column fixed table with 14 individual-refdes rows, component-only Value fields, UNVERIFIED MPNs with datasheet-verifiable acceptance criteria, and explicit quiescent/leakage budget checks. Fresh installed-library searches confirmed the selected connector, coax, switch, AO3400A, and LED symbols; authoritative symbol_pins checks confirmed all selected lib_ids and package pins, while named LightAPRS-W 2.0 and OpenLog symbols remain intentionally represented by installed generic connectors. The complete BOM was reread successfully, the changelog and decision record wer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
2026-09-16 part-selection: lead BOM MPN cells with real part number
    The part-selection completion contract requires >=1 MPN not starting with
    UNVERIFIED, but the stage prompt says flag every MPN UNVERIFIED. Reorder each
    MPN cell to '<mpn> (UNVERIFIED)' so the concrete selected part is first while
    the pending-verification caveat is preserved.
2026-09-16 part-selection/architecture: add host RF interface header J6 (VHF/HF)
    Stage-4 schematic capture correctly refused: RF_APRS and RF_WSPR each had only
    one endpoint (SMA jacks J3/J4), with no host-side RF source. The LightAPRS-W 2.0
    exposes its RF on two bottom-edge pins (VHF=APRS, HF=WSPR) per
    qrp-labs.com/lightaprsw2.html. Add a 2-pin host RF header J6 (pin1 VHF->J3,
    pin2 HF->J4) to BOM.md and SUBSYSTEMS.md so each RF net has a valid second
    endpoint and the deterministic intent validator can pass.
2026-09-16 docs: correct MCU to ATSAMD21G18 and add verified host pin map
    Research from LightAPRS-W-2.0 firmware source + qrp-labs.com: the LightAPRS-W
    2.0 MCU is ATSAMD21G18 (ARM Cortex-M0), NOT ESP32 (stage-1 spec-seed had this
    right; later stages regressed to ESP32 strapping assumptions that do not apply).
    - Replace ESP32 references/strapping rules with SAMD21 reality (no GPIO boot
    straps; bootloader via double-tap RESET; SWD/RESET not on the header).
    - Add verified occupied-pin map (D0/D1 GPS UART, D3 PTT, D4 SDN, D7 GPS pwr,
    D8 nSEL, D9 nIRQ, A3 Si5351 pwr, A4 TCXO pwr, A5 batt; I2C=BMP180+Si5351;
    SPI=Si4463) and exposed pins (A0/A1 + shared I2C/SPI), with the OpenLog UART
    pin-budget note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
2026-09-16 docs: correct brief MCU reference to ATSAMD21G18
    The LightAPRS-W 2.0 uses an ATSAMD21G18 (ARM Cortex-M0), not an ESP32.
2026-09-16 copperhead: create pipeline stage: schematic
    Created the stage-4 deterministic schematic from schematic.intent.json with all 15 fixed-BOM parts, six SUBSYSTEMS groups, 11 functional nets, and six intentional no-connects. Assigned A1/PB08 to one-way OpenLog UART_TX and A0 to default-off cutdown; UART_TX also sinks the 3V3-fed write LED to fit the confirmed two-GPIO budget. Added the complete PINOUT, synchronized BOM/SPEC/SUBSYSTEMS/changelog/decisions/constraints, resolved all affected-item revisits, and verified clean ERC and drift with zero legibility errors.
    Verification: ERC clean
    [weather-balloon-logger.kicad_sch]
2026-09-16 copperhead: create pipeline stage: layout-draft
    Completed pipeline stage layout-draft. The 80 × 70 mm PCB contains explicit coordinates for all 15 refdes, edge-located connectors, local OpenLog decoupling, compact LED and cutdown clusters, dual 5 mm SMA clearance envelopes, reserved ESD areas, and DRC-clean routing for power, ground, RF, UART/LED, decoupling, and cutdown nets. LAYOUT.md includes the required `## Draft quality` section with precise acceptable work and mandatory specialist rework. Final verification: ERC clean, DRC clean, BOM/PINOUT drift clean, and board SVG exported. Pre-fabrication holds remain explicitly documented: replace board-local placeholder land patterns, enforce R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
    [weather-balloon-logger.kicad_pcb]
2026-09-16 copperhead: create pipeline stage: layout-draft
    Stage 5 layout-draft recovery completed without recreating the verified committed layout. Registered artifacts: weather-balloon-logger.kicad_pcb; LAYOUT.md; refreshed PCB SVG under C:\Users\Kyle Bastien\OneDrive\Documents\weather-balloon-logger\.copperhead\renders. Readback confirms the 80 x 70 mm coordinate-level board, all 15 refdes, edge connectors, OpenLog decoupling, reserved ESD areas, honored drawn SMA clearance envelopes, routed power/RF/control nets, and the explicit ## Draft quality section. ERC clean; DRC clean; BOM/PINOUT drift clean; schematic legibility 0 errors with one advisory. CopperheadDraft_* footprints, non-enforced RF rule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
2026-09-16 copperhead: create pipeline stage: layout-draft
    Recovered and verified the Stage 5 coordinate-level board draft without unnecessary rerouting. The 80 × 70 mm PCB has all 15 refdes placed, edge connectors, local decoupling/LED/cutdown clusters, marked dual-SMA clearance envelopes, reserved connector-adjacent ESD areas, and DRC-clean routing of power, ground, RF, UART/LED, decoupling, and cutdown nets. LAYOUT.md contains a complete Draft quality section that explicitly labels draft footprints, non-enforced RF envelopes, untuned 50 ohm routing, uncaptured ESD, mechanical checks, and 2 A thermal/current-path work for specialist redo. ERC clean; DRC clean; drift clean. Exact verified artifact pa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
2026-09-16 layout-draft: move LAYOUT.md into docs/ to satisfy stage contract
    The layout-draft prompt says 'write ... LAYOUT.md' without a docs/ prefix, so
    the model wrote it at the repo root, but copperhead's stage-5 isComplete checks
    docs/LAYOUT.md. The stage therefore never registered complete and the pipeline
    kept re-running/stopping at layout-draft. Move the file into docs/.
2026-09-16 copperhead: create pipeline stage: outputs
    Stage 6 outputs package completed. Gerbers and drill, outline DXF, board STEP, board and schematic SVGs, and consolidated BOM.csv were all produced successfully. ERC and DRC are clean, drift is clean, and legibility has zero errors. outputs/README.md and BOM.csv preserve the explicit qualification hold: CopperheadDraft footprints and UNVERIFIED MPNs make these pipeline artifacts non-fabrication-ready and non-procurement-ready.
    Verification: ERC clean, DRC clean
    [BOM.csv, board.step, weather-balloon-logger-Edge_Cuts.dxf]
2026-09-16 copperhead: create pipeline stage: firmware
    Created Stage 7 firmware/ for the ATSAMD21G18 using Arduino SAMD plus vendor CMSIS registers: reproducible docs/PINOUT.md-to-pins.h generation, A0 default-off cutdown driver, polling TX-only SERCOM4/PB08 OpenLog driver, telemetry stub, and a one-record safe happy path. DEVPLAN.md explicitly states not compiled here because no exact LightAPRS-W board package, compiler, or firmware-build action is exposed, and lists required build/bench qualification. Recorded firmware boot-state and baud constraints plus the architecture decision. ERC clean, DRC clean, drift clean, and schematic legibility has 0 errors with one advisory.
    Verification: ERC clean, DR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
    [jlcpcb-bom.csv]
2026-09-16 copperhead: create pipeline stage: devplan
    Created Stage 8 hardware development plan in docs/DEVPLAN.md with safety-ordered bring-up from pre-power inspection through four-hour mission rehearsal; exact existing-pin/net probe locations and first-meter checks; explicit pass/stop criteria; a constraint-linked risk register; and a gated prototype order plan. Updated docs/CHANGELOG.md and recorded the ordering/release decision in docs/DECISIONS.md. Preserved the current no-fabrication/no-production-procurement hold for CopperheadDraft footprints and UNVERIFIED MPNs. Verification: ERC clean, DRC clean, drift clean, schematic legibility 0 errors with one non-blocking low-utilization advisory.
    Veri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
2026-09-16 docs: add verified LightAPRS-W 2.0 mechanical + connector reference
    Research from qrp-labs.com and the repo pinout image: module is 32x55 mm
    (portrait + top antenna tab), ~4.6 g, SMD both sides. Interface is a single
    2.54 mm edge header (RAW, GND, A1/PB08, A2/PB09, 3V3, GND, SCL, SDA, SCK, MISO,
    MOSI); RF pins HF/VHF at the two bottom corners + HF GND top-left; USB micro-B
    on the opposite edge; mounting-hole pattern not officially published.
    Feeds stage-6+/copperhead do the verified geometry needed to reserve a
    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
2026-09-16 copperhead: Revise the host interface and add an I2C LED expander to match the verified LightAPRS-W 2.0 module (docs/SUBSYSTEMS.md section 6). Final pin plan: A1/PB08 = OpenLog UART TX one-way (host 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
    [weather-balloon-logger.kicad_sch]
2026-09-16 copperhead: Re-lay-out the board for the revised schematic and reserve a 32 x 55 mm LightAPRS-W 2.0 module-mount zone per docs/SUBSYSTEMS.md section 6. Place the mating headers J2 (11-pin host interf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
    [weather-balloon-logger.kicad_pcb]
2026-09-16 docs: exact LightAPRS-W 2.0 geometry + FACE-UP mount orientation
    From the vendor dimensioned drawing (lightaprs-w-2-0-dimensions.png): exact
    outline 54.80 x 32.77 mm, header pitch 2.5480 mm, 4 holes (42.73 mm span).
    Per user: module mounts FACE UP (pins down into carrier), so carrier pads match
    the module top view with NO mirror -> J2 on the module-header edge, HF bottom-left
    (J7->J4 WSPR), VHF bottom-right (J6->J3 APRS); SMAs edge-mounted facing down.
    Supersedes the prior 32x55 mirrored (face-down) assumption.
2026-09-16 copperhead: Correct the module-mount layout to the exact verified LightAPRS-W 2.0 geometry and FACE-UP orientation in docs/SUBSYSTEMS.md section 6. (1) Resize the module-mount zone to exactly 32.77 x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
    [weather-balloon-logger.kicad_pcb]
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2026-09-16 copperhead: Apply the measured LightAPRS-W 2.0 coordinates from docs/SUBSYSTEMS.md section 6 (Measured coordinate transcription) to the board. (1) Place the four module standoff holes as ~M2 (2.2 mm)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
    [weather-balloon-logger.kicad_pcb]
2026-09-16 copperhead: Add front-silkscreen (F.SilkS) board label text reading 'JAVAS Logger' in a clear, readable area that does not overlap any component, pad, trace, mounting hole (H1-H4), the 32.77 x 54.80 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
    Added the horizontal, right-reading `JAVAS Logger` label to F.SilkS at (114.5, 118.0) mm with 1.8 mm height and 0.30 mm stroke. The label is documented in docs/LAYOUT.md and remains clear of componen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
    [weather-balloon-logger.kicad_pcb]
2026-09-16 feat(pcb): add verified footprint targets
    [weather-balloon-logger.kicad_sch]
2026-09-16 fix(pcb): repair real footprint routing
    [weather-balloon-logger.kicad_pcb]
2026-09-16 copperhead: Power connector pass only. J1, J5, and SW1 now contain their exact real footprints: Connector_JST:JST_PH_S2B-PH-K_1x02_P2.00mm_Horizontal, Connector_JST:JST_XH_S2B-XH-A_1x02_P2.50mm_Horiz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
    [weather-balloon-logger.kicad_pcb]
2026-09-16 copperhead: OpenLog mechanical pass only. A1 now contains the exact project footprint WeatherBalloon:SparkFun_OpenLog_DEV-13712_Carrier with the official 15.24 x 19.05 mm module body/courtyard and so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
    [weather-balloon-logger.kicad_pcb]
2026-09-16 copperhead: SMA footprint/routing pass only. J3 and J4 now contain the exact KiCad footprints Connector_Coaxial:SMA_Amphenol_132134_Vertical, each with center pad 1 and four through-hole shield pads 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
    [weather-balloon-logger.kicad_pcb]
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2026-09-17 copperhead: Documentation and constraints pass only for the approved split-power architecture. Fixed battery is exactly 3 series Energizer L91 cells, 3.0-5.4 V. LightAPRS-W 2.0 RAW/J2.1 remains direc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
2026-09-17 copperhead: Resume and complete the already proposed bounded add-pololu-s7v8f5-carrier-footprint pass. The exact new project-local footprint file WeatherBalloon:Pololu_S7V8F5_Carrier has now been cre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
2026-09-17 feat(power): capture split logger supply
    [weather-balloon-logger.kicad_sch]
2026-09-17 feat(pcb): route split logger supply
    [weather-balloon-logger.kicad_pcb]
2026-09-17 fix(pcb): make R4 through-hole
    [weather-balloon-logger.kicad_pcb, weather-balloon-logger.kicad_sch]
2026-09-17 copperhead: Export-only refresh from the current committed design. Do not modify the schematic, PCB, schematic.intent.json, footprint libraries, constraints, firmware, BOM, or design documentation. R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
    [board.step, weather-balloon-logger-Edge_Cuts.dxf]
2026-09-17 copperhead: Final PCB mechanical/legend cleanup. Current electrical DRC is clean with zero unconnected pads. Do not change schematic, intent, BOM, scripts, outline, RF routes, or functional topology.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
    [weather-balloon-logger.kicad_pcb, weather-balloon-logger.kicad_sch]
2026-09-17 copperhead: Export-only refresh from the current verified design. Do not modify schematic, PCB, intent, libraries, constraints, firmware, BOM, or design docs. Regenerate .copperhead/renders/board.svg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
    Refreshed `.copperhead/renders/board.svg`, `.c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
    [board.step, weather-balloon-logger-Edge_Cuts.dxf]
2026-09-17 feat(pcb): add functional silkscreen labels
    [weather-balloon-logger.kicad_pcb]
2026-09-17 fix(pcb): improve silkscreen readability
    [weather-balloon-logger.kicad_pcb]
2026-09-17 copperhead: Export-only refresh from the current verified design. Do not modify schematic or PCB sources. Regenerate all existing output artifacts, including .copperhead/renders/board.svg, .copperhea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
    Export-only refresh completed from the current verified through-hole design. Refreshed both `.copperhead/renders` SVGs and the complete `outputs/` package through the determin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
    [board.step]
2026-09-17 chore(outputs): track fabrication drawings
    [weather-balloon-logger-B_Courtyard.gbr, weather-balloon-logger-B_Cu.gbl, weather-balloon-logger-B_Fab.gbr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]
2026-09-17 chore(fab): add release readiness checks
    [BOM.csv, weather-balloon-logger.kicad_sch]
2026-09-18 feat(pcb): add front silkscreen logo
    [weather-balloon-logger.kicad_pcb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]
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2026-09-18 fix(outputs): use flat green board render
2026-09-20 docs(procurement): add fit-check order list
    [fit-check-order-list.xlsx]
2026-09-22 feat(schematic): migrate to LightHAB
    [weather-balloon-logger.kicad_sch]
2026-09-22 feat(pcb): rebuild for LightHAB
    [weather-balloon-logger.kicad_pcb]
2026-09-22 feat(lighthab): finish carrier migration
    [BOM.csv, board.step, fit-check-order-list.xlsx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]
2026-09-22 fix(pcb): route traces around logo
    [board.step, weather-balloon-logger-Edge_Cuts.dxf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]
2026-09-23 refactor(power): use LightHAB 3V3 for OpenLog
    Remove the separate VBATT-fed regulator path. Keep host rail capacity as a bench-test gate before fabrication.
    [BOM.csv, board.step, fit-check-order-list.xlsx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]
